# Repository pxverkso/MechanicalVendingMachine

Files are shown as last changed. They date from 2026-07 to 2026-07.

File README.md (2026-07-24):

# Mechanical Vending Machine


## Why I made This
I made this Vending Machine for outreach events for my club. We are planning on giving away clicker fidgets and I thought it would be a nice interactive addition for people coming by our booth. 

## How does it work? 
It's hard to describe just how it works with words but basically the button is connected to a lever system that pushes a coin in the sorting chamber to push another lever, which is connected to the dispensing mechanism. If no coin is there, nothing happens, the lever in the sorting chamber pushes nothing so it can't activate the dispensing lever. 

# READ BELOW FOR ASSEMBLY

### No Motors and No Programming, the Mechanical Vending Machine Dispenses, Sorts, and Reloads Items with just a press of a single orange button. 
### I repeat, assembly instructions are on the Onshape project, you do not need an account to view and interact with the model.
## This functional vending machine can be printed and assembled easily using the Printables, Onshape, and Google Sheets Links Below.

** Note that any 2 rubberbands will be needed to provide tension on the button and output lever. 

## [Printables](https://www.printables.com/model/1781307-mechanical-vending-machine)
## [Onshape](https://cad.onshape.com/documents/10e2223a4cf293251d8bdfe9/w/6691115cbd0ce3181a4e7db5/e/503707b66b4a72e360bf7a65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)
## [Google Sheets List of Parts](https://docs.google.com/spreadsheets/d/1D1UvOK2qsuYQv0KvEngfw1f7PT8NvFq86jM__gl5EZ8/edit?usp=sharing) 
## [Demo Video Youtube](https://youtube.com/shorts/9fbig1VIGts?feature=share)

## Parts
| Part | Qty | Price | Link | Total |
|:-----|----:|:---|:-----|:---|
| M4 10mm Screw | 25 | $3.99 | [goBILDA](https://www.gobilda.com/m4-x-0-7mm-zinc-plated-socket-head-screw-10mm-length/?sku=2800-0004-0010) | $5.72 |
| M4 22mm Screw | 4 | $0.65 | [goBILDA](https://www.gobilda.com/m4-x-0-7mm-zinc-plated-socket-head-screw-22mm-length-25-pack/) | |
| M4 16mm Screw | 3 | $0.45 | [goBILDA](https://www.gobilda.com/m4-x-0-7mm-zinc-plated-socket-head-screw-16mm-length/) | |
| M4 1mm Shim | 5 | $0.46 | [goBILDA](https://www.gobilda.com/2807-series-stainless-steel-shim-4mm-id-x-7mm-od-1mm-thickness-12-pack/) | |
| M4 30mm Screw | 1 | $0.17 | [goBILDA](https://www.gobilda.com/m4-x-0-7mm-zinc-plated-socket-head-screw-30mm-length-25-pack/) | |
| **Grand Total** | | | | **$17.85** |

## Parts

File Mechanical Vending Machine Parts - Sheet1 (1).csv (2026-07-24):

Part Link + Name | # Needed for Build | $ Needed for Build | Link to parts | Total For Build | Total
M4 10MM | 25 | $3.99 | https://www.gobilda.com/m4-x-0-7mm-zinc-plated-socket-head-screw-10mm-length/?sku=2800-0004-0010 | $5.72 | $17.85
M4 22MM | 4 | $0.65 | https://www.gobilda.com/m4-x-0-7mm-zinc-plated-socket-head-screw-22mm-length-25-pack/
M4 16MM | 3 | $0.45 | https://www.gobilda.com/m4-x-0-7mm-zinc-plated-socket-head-screw-16mm-length/
M4 1MM Shim | 5 | $0.46 | https://www.gobilda.com/2807-series-stainless-steel-shim-4mm-id-x-7mm-od-1mm-thickness-12-pack/
M4 30MM | 1 | $0.17 | https://www.gobilda.com/m4-x-0-7mm-zinc-plated-socket-head-screw-30mm-length-25-pack/

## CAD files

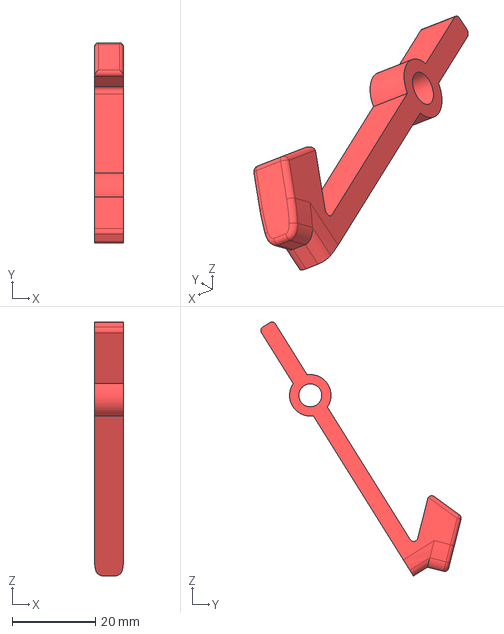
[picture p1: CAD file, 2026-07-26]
STEP MechVendingMachine Parts/Assembly 1 - Coin Push Lever.step
7.00 x 48.2 x 61.1 mm

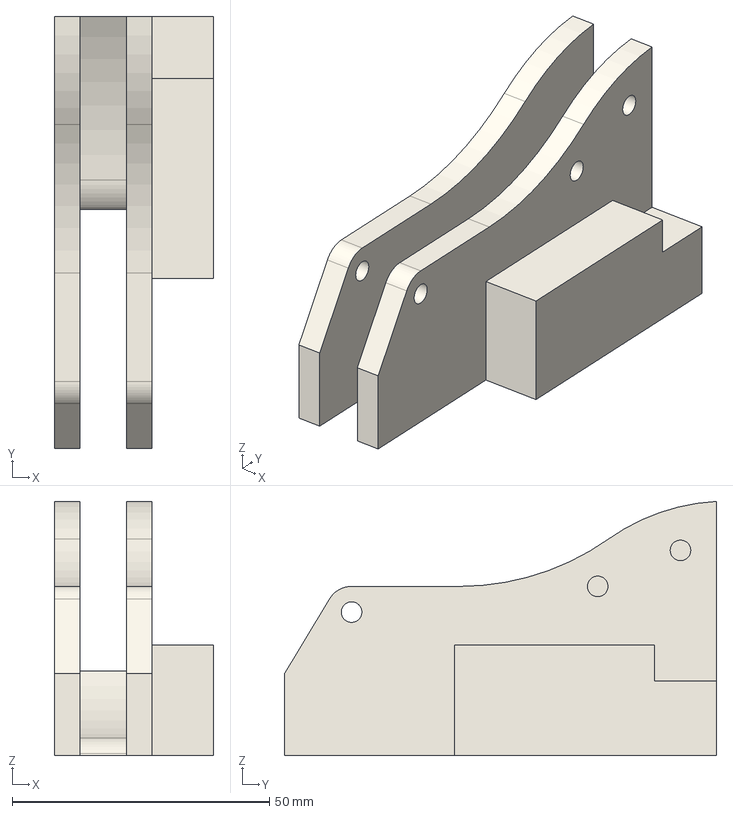
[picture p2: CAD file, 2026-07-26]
STEP MechVendingMachine Parts/Assembly 1 - Coin Insert Housing.step
31.0 x 84.0 x 49.4 mm

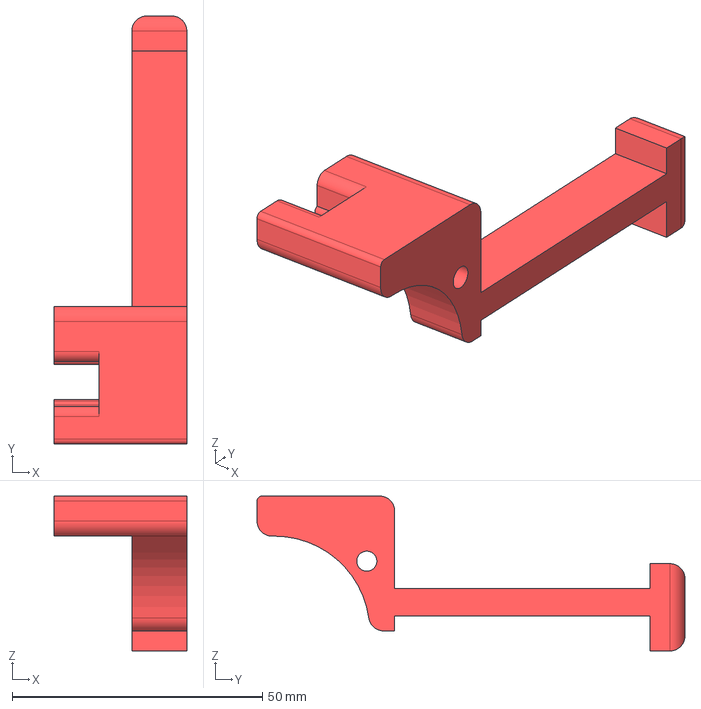
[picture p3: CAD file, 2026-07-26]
STEP MechVendingMachine Parts/Assembly 1 - Button + Lever.step
26.5 x 85.5 x 30.9 mm

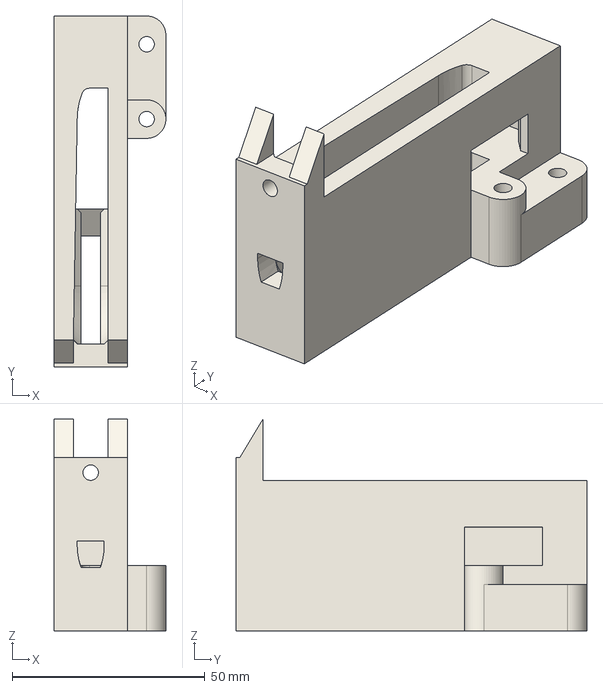
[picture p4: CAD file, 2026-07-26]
STEP MechVendingMachine Parts/Assembly 1 - Coin Sorting and Output Housing.step
29.0 x 91.0 x 55.0 mm

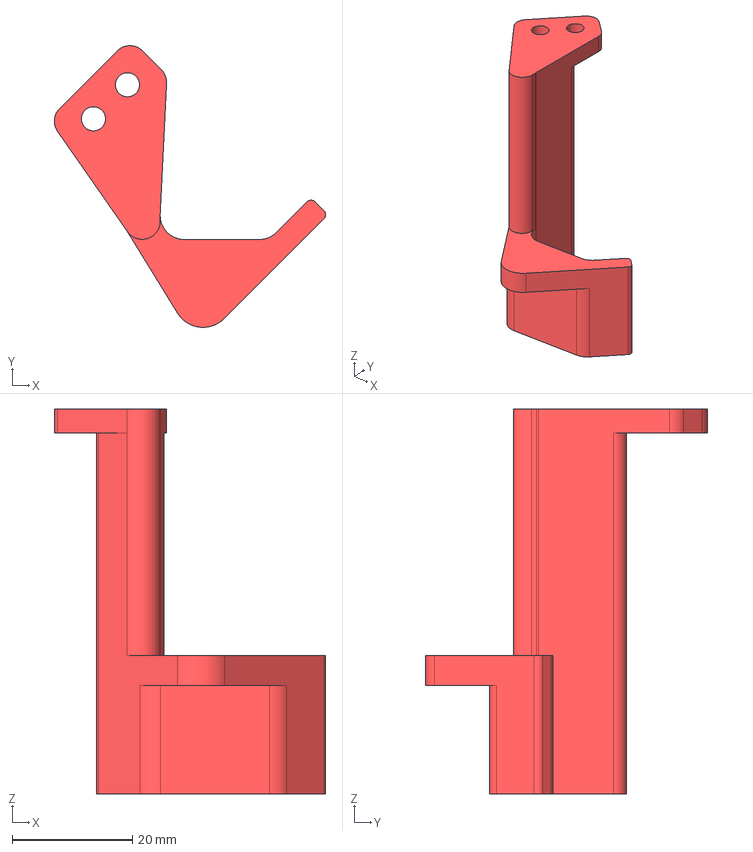
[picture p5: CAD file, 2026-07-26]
STEP MechVendingMachine Parts/Assembly 1 - Output Lever (3).step
45.1 x 46.8 x 64.0 mm

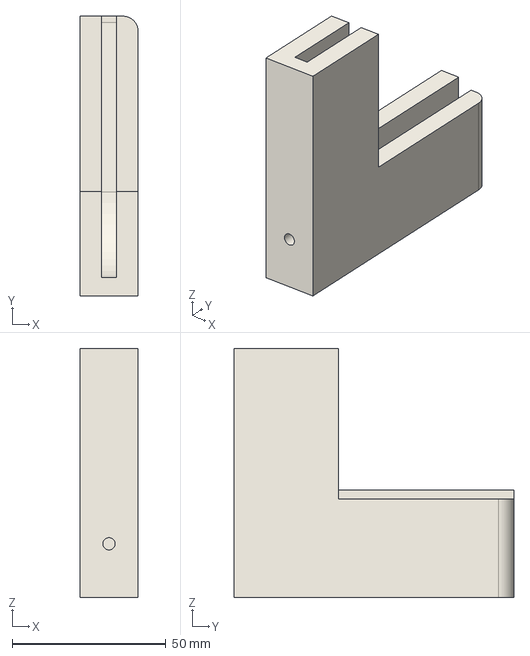
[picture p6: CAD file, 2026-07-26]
STEP MechVendingMachine Parts/Assembly 1 - Sorted Coin Output.step
19.0 x 91.0 x 81.0 mm

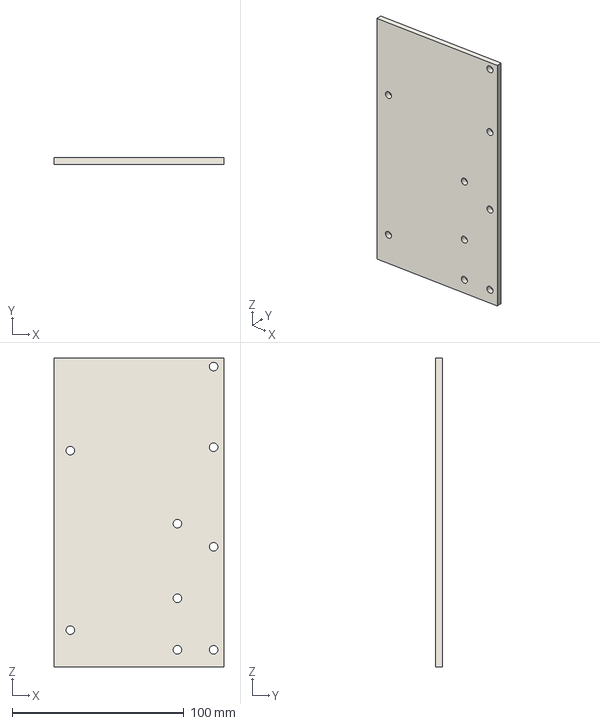
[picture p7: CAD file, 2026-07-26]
STEP MechVendingMachine Parts/Assembly 1 - Back Wall.step
99.0 x 4.00 x 180.0 mm

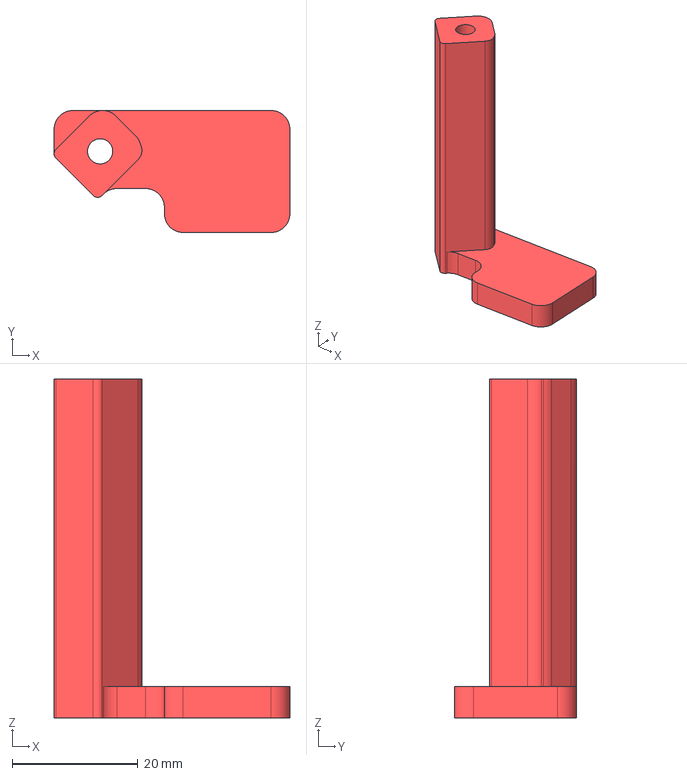
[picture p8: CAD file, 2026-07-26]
STEP MechVendingMachine Parts/Assembly 1 - Output Lever (2).step
37.6 x 19.4 x 54.0 mm

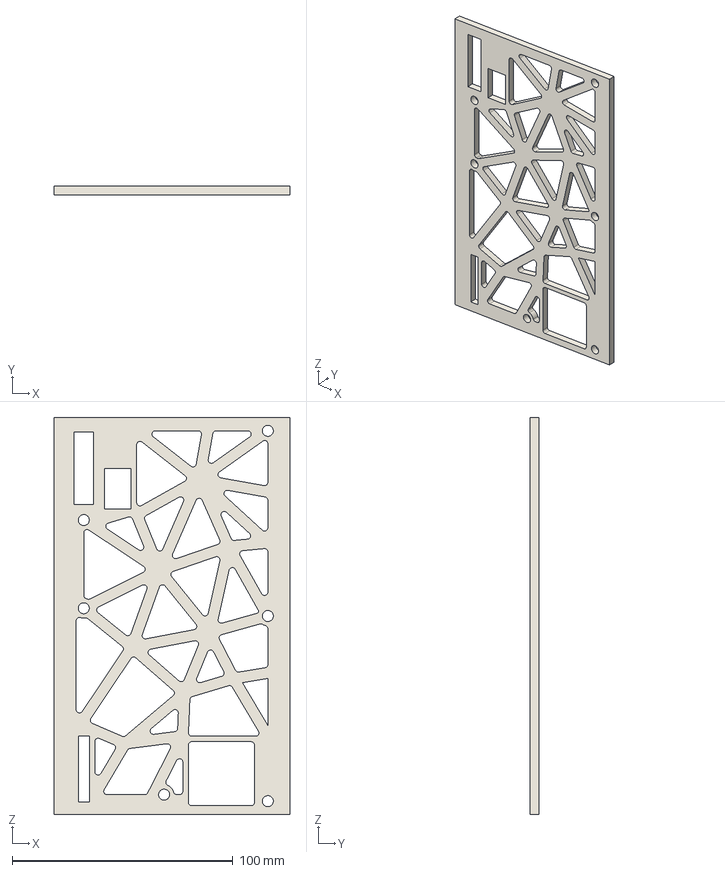
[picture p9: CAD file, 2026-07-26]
STEP MechVendingMachine Parts/Assembly 1 - Front.step
107.0 x 4.00 x 180.0 mm

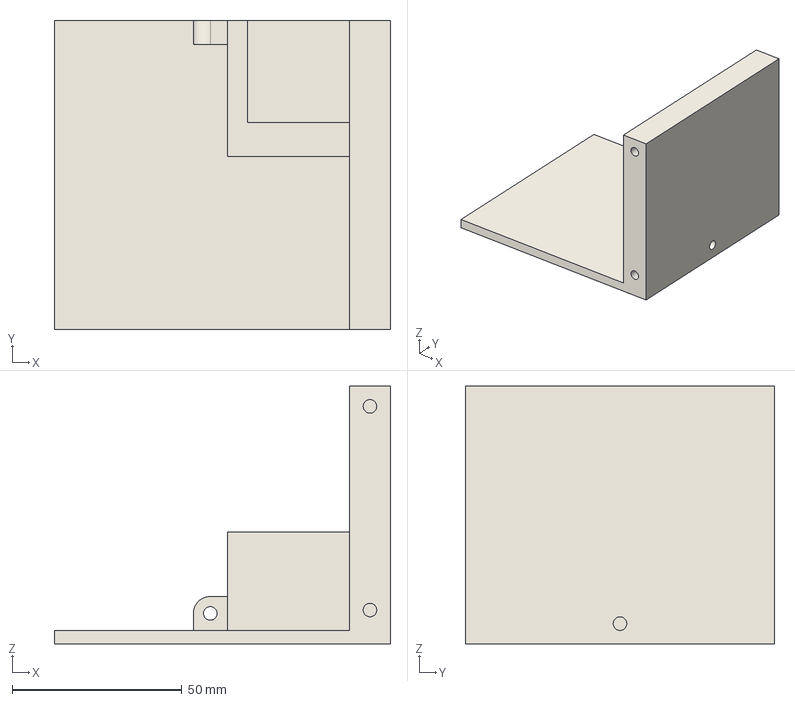
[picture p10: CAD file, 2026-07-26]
STEP MechVendingMachine Parts/Assembly 1 - Base.step
99.0 x 91.0 x 76.0 mm

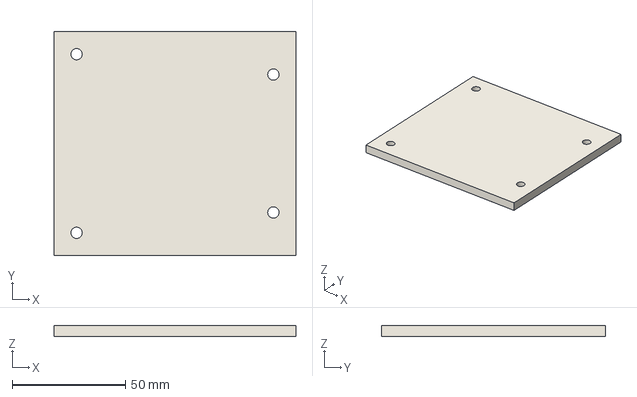
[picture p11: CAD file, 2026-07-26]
STEP MechVendingMachine Parts/Assembly 1 - Lid.step
107.0 x 99.0 x 5.00 mm

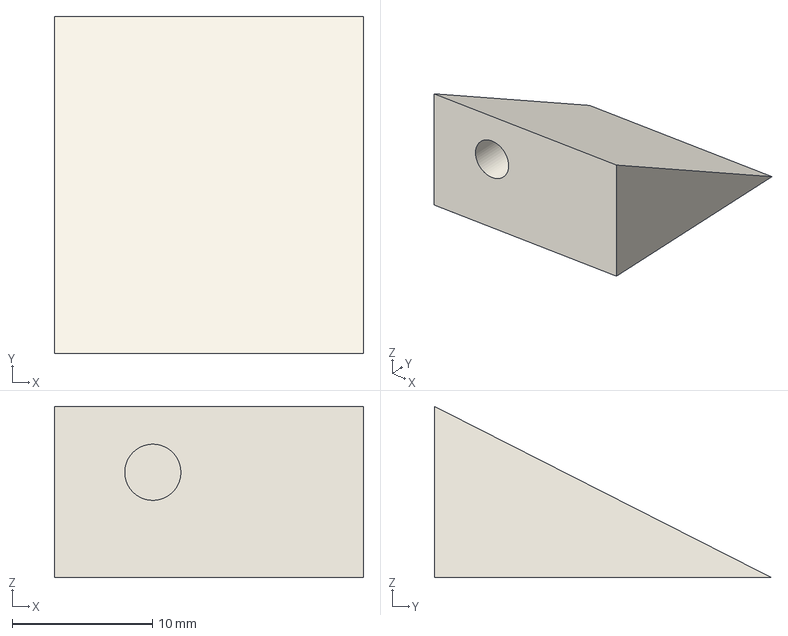
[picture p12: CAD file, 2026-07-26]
STEP MechVendingMachine Parts/Assembly 1 - Reload Ramp.step
22.0 x 24.0 x 12.2 mm

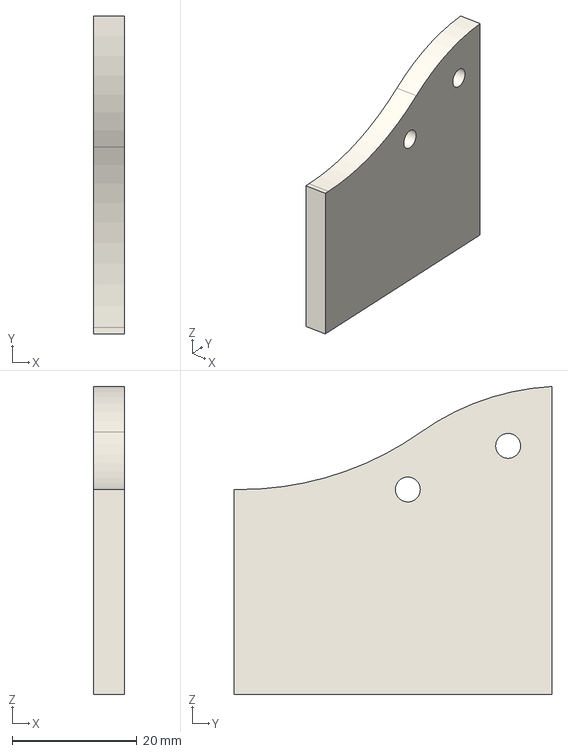
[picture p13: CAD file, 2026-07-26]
STEP MechVendingMachine Parts/Assembly 1 - Button Housing.step
5.00 x 51.0 x 49.4 mm

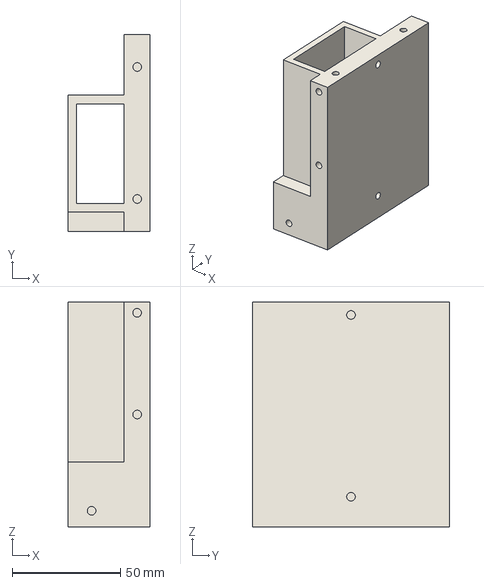
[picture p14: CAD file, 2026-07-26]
STEP MechVendingMachine Parts/Assembly 1 - Reload Shute.step
38.1 x 91.0 x 104.0 mm

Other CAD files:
STEP MechVendingMachine Parts/Assembly 1 - Coin Bin.step
STEP MechVendingMachine Parts/Assembly 1 - Button Spacer.step
STEP MechVendingMachine Parts/Assembly 1 - Coin Bin Rail.step
STEP MechVendingMachine Parts/Assembly 1 - Left Wall.step
STEP MechVendingMachine Parts/Assembly 1 - Coin Bin Wall.step
STEP MechVendingMachine Parts/Assembly 1 - Output Lever (1).step
STEP MechVendingMachine Parts/Assembly 1 - Reload Ramp (1).step
STL MechVendingMachine Parts/Assembly 1 - Back Wall.stl
STL MechVendingMachine Parts/Assembly 1 - Base.stl
STL MechVendingMachine Parts/Assembly 1 - Button + Lever.stl
STL MechVendingMachine Parts/Assembly 1 - Button Housing.stl
STL MechVendingMachine Parts/Assembly 1 - Button Spacer.stl
STL MechVendingMachine Parts/Assembly 1 - Coin Bin Rail.stl
STL MechVendingMachine Parts/Assembly 1 - Coin Bin Wall.stl
STL MechVendingMachine Parts/Assembly 1 - Coin Bin.stl
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

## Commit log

2026-07-24 Update README with assembly instructions and parts list
    Added assembly instructions and parts list for the Mechanical Vending Machine.
2026-07-24 Update README with assembly instructions and resources
    Added assembly instructions and links for the Mechanical Vending Machine.
